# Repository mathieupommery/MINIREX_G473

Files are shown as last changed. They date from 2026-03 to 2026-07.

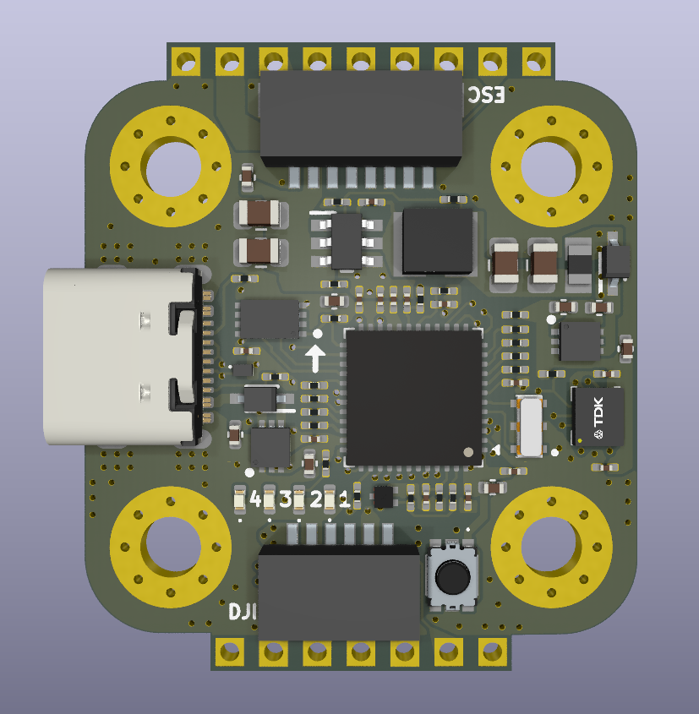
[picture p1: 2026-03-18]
DOC/front.png

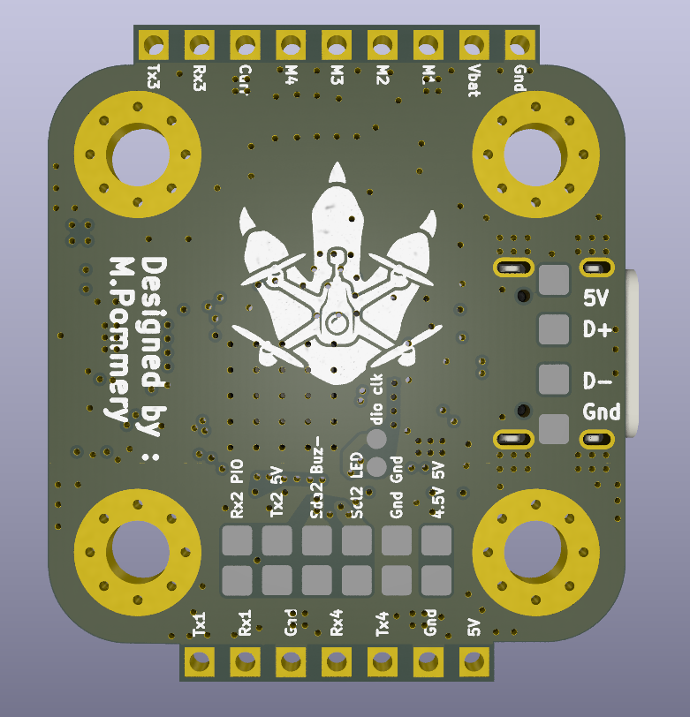
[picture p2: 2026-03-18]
DOC/back.png

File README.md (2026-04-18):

# STM32G473 Flight Controller (20x20mm)

# NEWS : 
* V2 reduced cost by changing part of the compoment to asian brand, assembly now possible with jlc and lcsc part stock, a price per unit produced graph is disponible below 

## Overview
High-performance flight controller based on the **STM32G473** MCU, featuring a compact 20x20mm mounting pattern. This board is specifically designed for high-voltage builds (up to 12S) and high-speed processing, utilizing a 6-layer PCB stackup with all components mounted on a single side for optimal integration and cooling.
## Hardware Visuals

### PCB View (V1)
with_coin
### CAD View (V1)

    

## Technical Specifications
### Core System
* **MCU:** STM32G473 (Cortex-M4, 170MHz)
* **IMU:** ICM-42688-P (Ultra-low noise 6-axis gyro)
* **Blackbox:** 16M-bit (2MB) Onboard Flash
* **PCB:** 6-layer, single-sided compoment 

### Power Management
* **Main Buck Regulator:** LMR51625
    * **Input Voltage:** 7V to 55V
    * **Output:** 5V @ 2.5A Max
* **Dual LDO Regulation:** Two independent LDL212PV33R (1.2A each)
    * **LDO 1:** Dedicated to MCU and Flash memory
    * **LDO 2:** Dedicated to the ICM-42688-P sensor for maximum signal purity

### Protection & Hardware Robustness
* **USB Protection:** Integrated **TVS Diodes** (Transient Voltage Suppressors) on the USB port to protect the MCU against electrostatic discharge (ESD) and short-circuits caused by humidity or debris.
* **Filtering:** High-quality ceramic capacitors and dedicated power planes for a low noise floor.

### Connectivity & Interface
* **Connectors:** 2x JST-SH 1.0mm ports (DJI/Digital VTX and ESC)
* **Status LEDs:** 4x Onboard diagnostic LEDs:
    * 2x Betaflight Status (Green/Blue)
    * 1x 3.3V MCU Power
    * 1x 3.3V Sensor Power
    * many soldering pads to add GPS, buzzer, led, or IO 

## Cost (BOM)
## Bill of Materials (BOM) Cost Estimation

The following table demonstrates the estimated component costs based on Mouser volume pricing. The unit price of each component dynamically adapts to the total quantity required for the entire production batch (1, 100, or 1000 boards). 

*Prices are estimates in USD and do not include PCB manufacturing or assembly costs.*

| Component / Value | Mouser Ref. | Qty/Board | Unit Price (1 Bd) | Unit Price (100 Bds) | Unit Price (1k Bds) | Total 1 Bd | Total 100 Bds | Total 1k Bds |
| :--- | :--- | :---: | :---: | :---: | :---: | :---: | :---: | :---: |
| 100n | 710-885012104005 | 13 | $0.080 | $0.010 | $0.004 | $1.04 | $13.00 | $52.00 |
| 10n | 710-885012104014 | 1 | $0.120 | $0.030 | $0.010 | $0.12 | $3.00 | $10.00 |
| 1u | 710-885012105012 | 3 | $0.180 | $0.060 | $0.030 | $0.54 | $18.00 | $90.00 |
| 4.7u | 710-885012105012 | 3 | $0.180 | $0.060 | $0.030 | $0.54 | $18.00 | $90.00 |
| 0.1u | 81-GRM155R62A104ME4J | 1 | $0.100 | $0.020 | $0.010 | $0.10 | $2.00 | $10.00 |
| 2.2u | 710-885012105007 | 1 | $0.220 | $0.080 | $0.040 | $0.22 | $8.00 | $40.00 |
| 2.2u | 81-GRT21BD72A225KE13 | 2 | $0.240 | $0.090 | $0.050 | $0.48 | $18.00 | $100.00 |
| 47u | 81-GRM21BR61A476ME5K | 2 | $0.550 | $0.220 | $0.120 | $1.10 | $44.00 | $240.00 |
| USB4110-GF-A | 710-629722000214 | 1 | $1.150 | $0.850 | $0.650 | $1.15 | $85.00 | $650.00 |
| LED 150040BS73240 (Blue) | 710-150040BS73240 | 1 | $0.260 | $0.120 | $0.080 | $0.26 | $12.00 | $80.00 |
| LED 150040GS73240 (Green) | 710-150040GS73240 | 1 | $0.260 | $0.120 | $0.080 | $0.26 | $12.00 | $80.00 |
| LED 150040RS73240 (Red) | 710-150040RS73240 | 2 | $0.260 | $0.120 | $0.080 | $0.52 | $24.00 | $160.00 |
| STM32G473CEU6 | 511-STM32G473CEU6 | 1 | $7.580 | $5.450 | $4.800 | $7.58 | $545.00 | $4800.00 |
| 5.1k | 667-ERJ-1GNF5101C | 2 | $0.100 | $0.010 | $0.005 | $0.20 | $2.00 | $10.00 |
| 100k | 667-ERJ-1GNF1003C | 2 | $0.100 | $0.010 | $0.005 | $0.20 | $2.00 | $10.00 |
| 10k | 667-ERJ-1GNF1002C | 3 | $0.100 | $0.010 | $0.005 | $0.30 | $3.00 | $15.00 |
| 1k | 667-ERJ-1GNF1001C | 6 | $0.100 | $0.010 | $0.005 | $0.60 | $6.00 | $30.00 |
| 20k | 667-ERJ-1GNF2002C | 1 | $0.100 | $0.010 | $0.005 | $0.10 | $1.00 | $5.00 |
| 19.1k | 667-ERJ-1GNF1912C | 1 | $0.100 | $0.010 | $0.005 | $0.10 | $1.00 | $5.00 |
| 22R | 667-ERJ-1GNF22R0C | 7 | $0.100 | $0.010 | $0.005 | $0.70 | $7.00 | $35.00 |
| 100R | 667-ERJ-1GNF1000C | 1 | $0.100 | $0.010 | $0.005 | $0.10 | $1.00 | $5.00 |
| Ferrite 74279220800 | 710-74279220800 | 1 | $0.140 | $0.040 | $0.020 | $0.14 | $4.00 | $20.00 |
| Inductor 74479335329247 | 710-74479335329247 | 1 | $0.780 | $0.450 | $0.320 | $0.78 | $45.00 | $320.00 |
| JST SH 6-pin | 306-M06BSRSSTBLFSNPP | 1 | $0.640 | $0.420 | $0.310 | $0.64 | $42.00 | $310.00 |
| LDO LDL212PV33R | 511-LDL212PV33R | 2 | $0.530 | $0.380 | $0.280 | $1.06 | $76.00 | $560.00 |
| Flash MX25R1635FZUIH0 | 95-25R1635FZUIH0TR | 1 | $1.840 | $1.150 | $0.950 | $1.84 | $115.00 | $950.00 |
| TVS SP3222-02ETG | 576-SP3222-02ETG | 1 | $0.420 | $0.220 | $0.150 | $0.42 | $22.00 | $150.00 |
| Switch 435151014824 | 710-435151014824 | 1 | $0.850 | $0.520 | $0.380 | $0.85 | $52.00 | $380.00 |
| MOSFET 2N7002KQBZ | 771-2N7002KQBZ | 1 | $0.180 | $0.060 | $0.030 | $0.18 | $6.00 | $30.00 |
| Osc CSTNE8M00GH5C000R0 | 81-CSTNE8M00GH5C000R | 1 | $0.450 | $0.240 | $0.160 | $0.45 | $24.00 | $160.00 |
| IMU ICM-42688-P | 410-ICM-42688-P | 1 | $4.860 | $3.550 | $2.900 | $4.86 | $355.00 | $2900.00 |
| JST SH 8-pin | 306-SM08BSRSSTB | 1 | $0.720 | $0.480 | $0.350 | $0.72 | $48.00 | $350.00 |
| Diode BAT60JFILM | 511-BAT60JFILM | 2 | $0.280 | $0.110 | $0.060 | $0.56 | $22.00 | $120.00 |
| Buck LMR51625YFDDCR | 595-LMR51625YFDDCR | 1 | $1.250 | $0.880 | $0.650 | $1.25 | $88.00 | $650.00 |
| **TOTAL COST (BOM)** | **-** | **-** | **-** | **-** | **-** | **$29.96** | **$1724.00** | **$13417.00** |
| **AVERAGE PRICE PER BOARD** | **-** | **-** | **-** | **-** | **-** | **$29.96** | **$17.24** | **$13.42** |

## Cost (BOM) V2
V2 version is here for cost optimisation purposes and for the possibility to assemble it completly on jlcpcb with lcsc compoment part, i changed few compoment like Nmos for buzzer or boot button, and i priviledged asian brand here is a graph with the cost per unit according to unit produced : 

costvsunit

## Hardware Design Principles
The 6-layer design ensures superior EMI shielding and thermal dissipation. 
stackup: signal-gnd-signal-gnd-power-gnd   
provide shielded power from signal and from the outside.

## Result and test : 

### Before reflow : 
before_reflow

###  Mounted on apex evo 5 inch : 

mounted

###  Test in fly :

> La vidéo de démonstration est disponible ici : [DOC/image_v1/video.mp4](./DOC/v1_image/vid.mp4)

## License
Creative Commons Attribution-NonCommercial-ShareAlike 4.0 International.

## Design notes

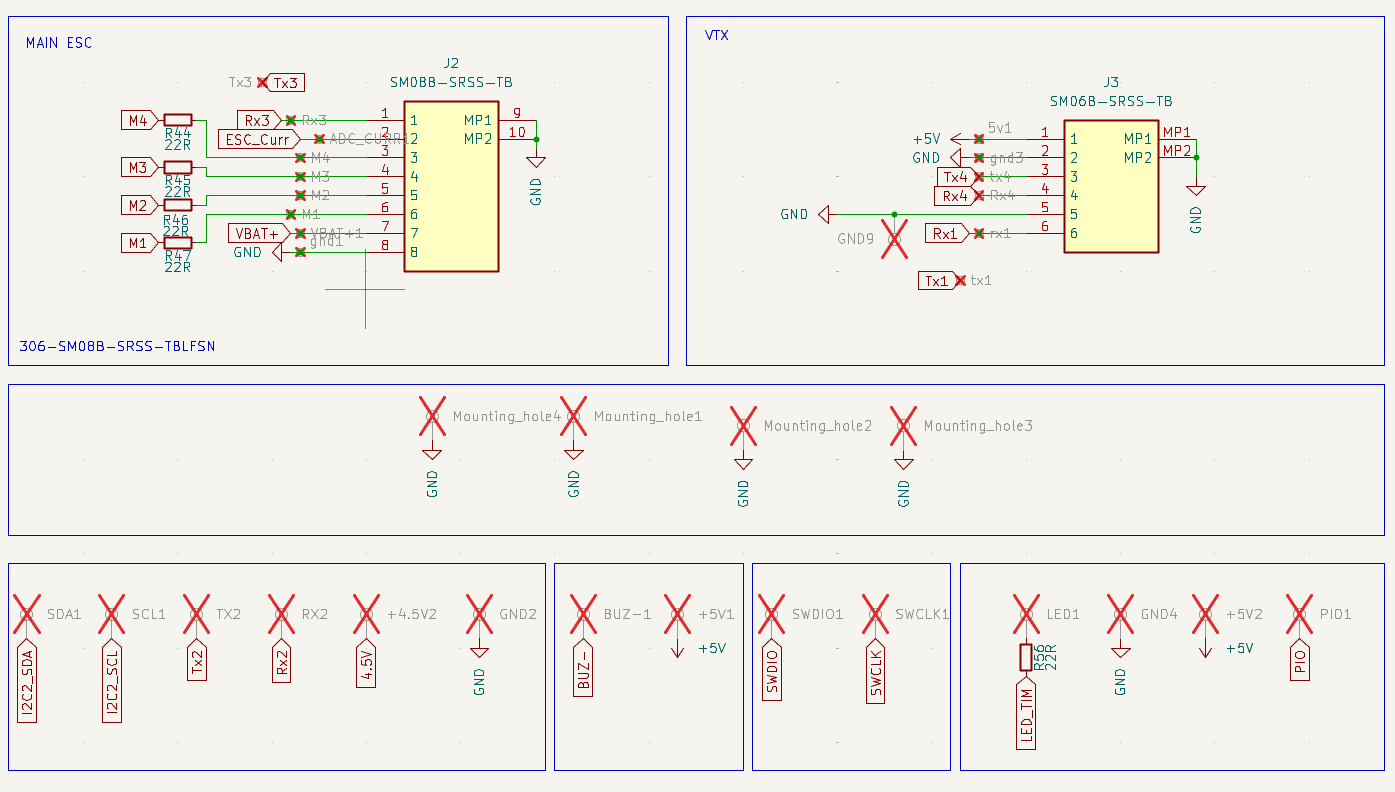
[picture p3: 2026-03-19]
DOC/sh4.png

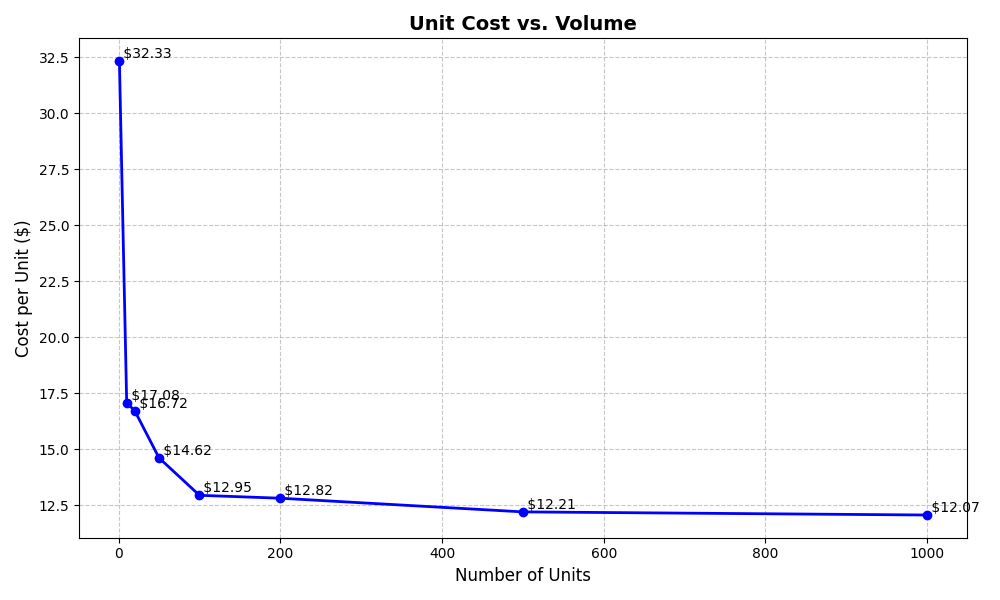
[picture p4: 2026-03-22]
DOC/costvsunit.png

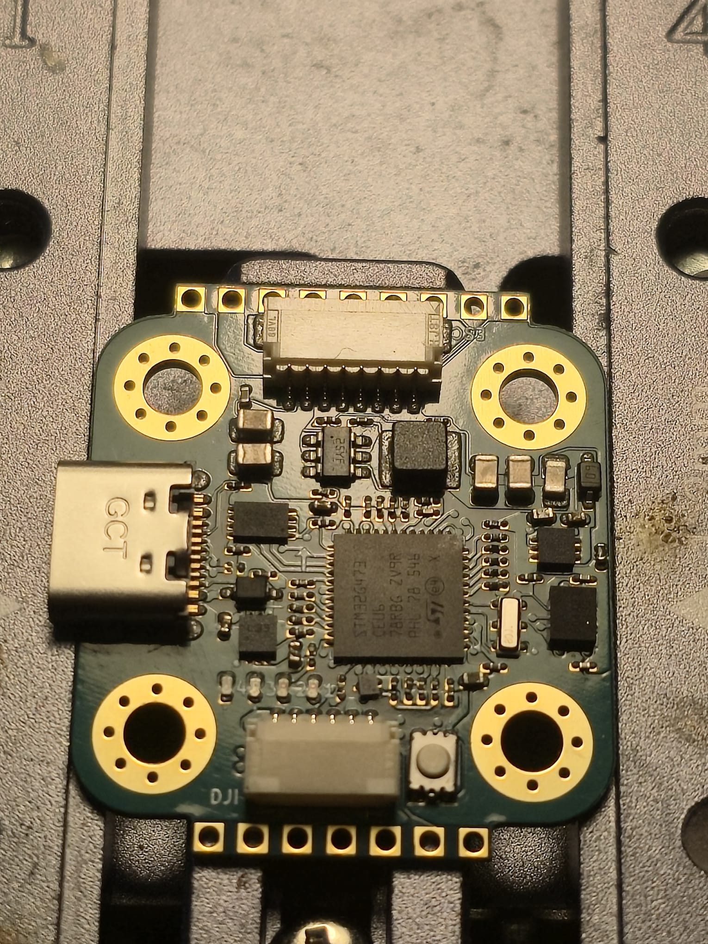
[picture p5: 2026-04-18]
DOC/v1_image/before_reflow.jpeg

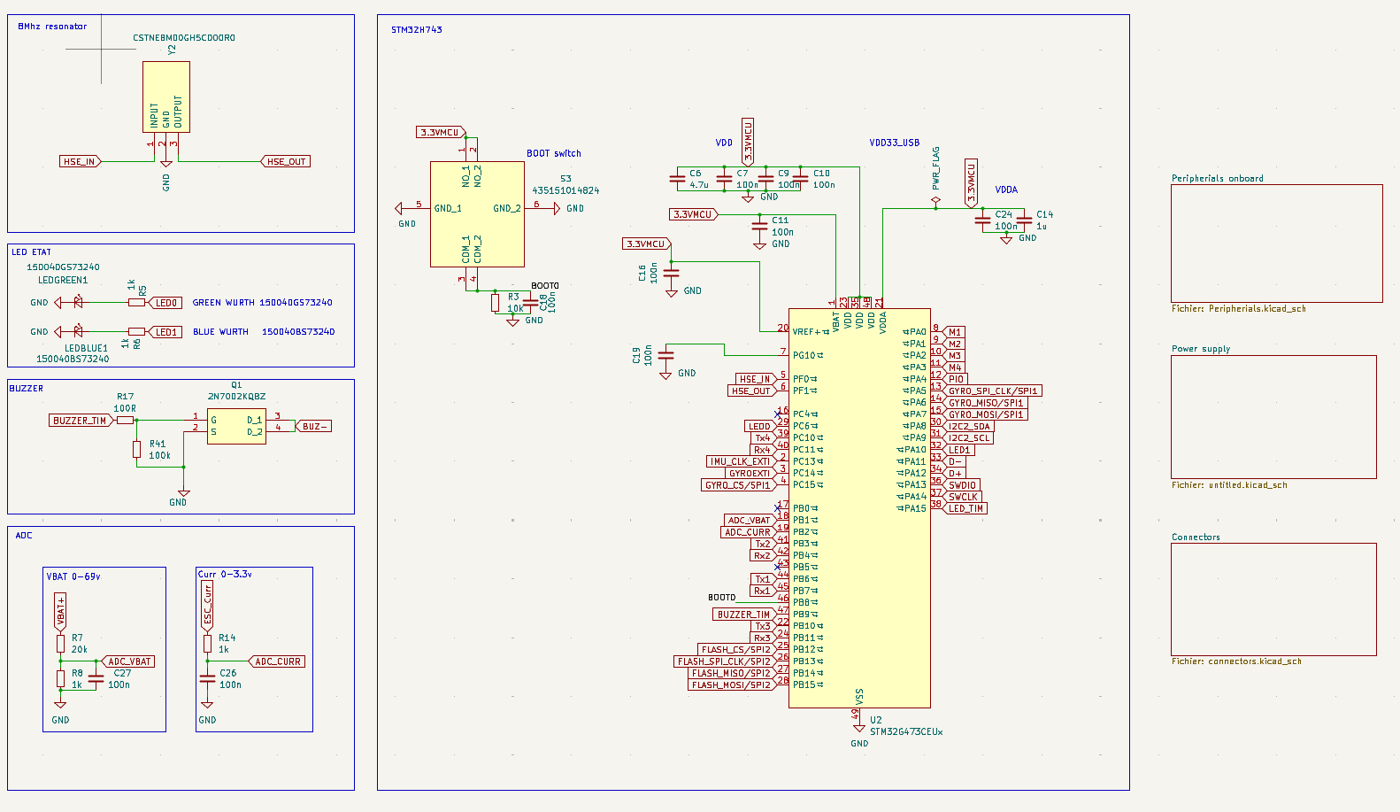
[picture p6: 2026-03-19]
DOC/sh1.png

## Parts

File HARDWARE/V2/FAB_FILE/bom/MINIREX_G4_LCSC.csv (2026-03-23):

Designator | Comment | Manufacturer_Part_Number | LCSC Part Number
LEDRED3,LEDRED4 | 150040RS73240 | TZ-P2-0402RTIA1-0.45T | C779449
LEDGREEN1 | 150040GS73240 | SZYY0402G | C434446
LEDBLUE1 | 150040BS73240 | XL-1005UBC | C22355736
L1 | ZEPIM303020D-4R7M | ZEPIM303020D-4R7M | C49009083
J1 | USB4105-GF-A | USB4105-GF-A | C3025063
FB1 | MPZ2012S101ATD25 | MPZ2012S101ATD25 | C307776
C21 | 2.2u | CC0402KRX5R7BB225 | C326556
C7,C9,C10,C11,C12,C16,C18,C19,C20,C22,C24,C25,C26,C27 | 100n | CC0201KRX5R8BB104 | C718252
C2,C6,C23 | 4.7u | CC0402MRX5R7BB475 | C723999
C1,C3,C14 | 1u | CC0402KRX5R7BB105 | C325464
IC2 | LMR51625YFDDCR | LMR51625YFDDCR | C45262768
IC1 | ICM-42688P | ICM-42688P | C46550687
U2 | STM32G473CEUx | STM32G473CEU6 | C1342773
IC4,IC5 | LDL212PV33R | LDL212PV33R | C2969892
D10,D11 | BAT60JFILM | BAT60JFILM | C133103
S1 | TS2306A-240GF-MSM-9_C388290 | TS2306A-240GF-MSM-9_C388290 | C2976675
R13,R17,R44,R45,R46,R47,R56,R61 | 47R | RC0201FR-0747RL | C273279
R5,R6,R8,R14,R21,R22 | 1k | RC0201FR-071KL | C138165
R3,R7,R9,R11,R15 | 19.1k | RC0201FR-0719K6L | C474565
R2,R41 | 100k | RC0201FR-07100KL | C106224
R1,R10 | 5.1k | RC0201FR-075K1L | C274341
Q2 | PMZB150UNEYL | TPM2025NP3 | C49230916
Y2 | CSTNE8M00GH5C000R0 | CSTNE8M00GH5C000R0 | C341525
C8,C17 | 47u | GRM21BR61A476ME15K | C2292827
C5 | 0.1u | GRM155R62A104KE14D | C162178
C4,C13 | 2.2u | GRM21BD72A225KE01L | C2981733
IC3 | ZD25WQ32CEIGR | ZD25WQ32CEIGR | C5258281
D1 | TPSP3222-02ETG | TPSP3222-02ETG | C47117640
J3 | SM06B-SRSS-TB | SM06B-SRSS-TB | C160405
J2 | SM08B-SRSS-TB | SM08B-SRSS-TB | C160407

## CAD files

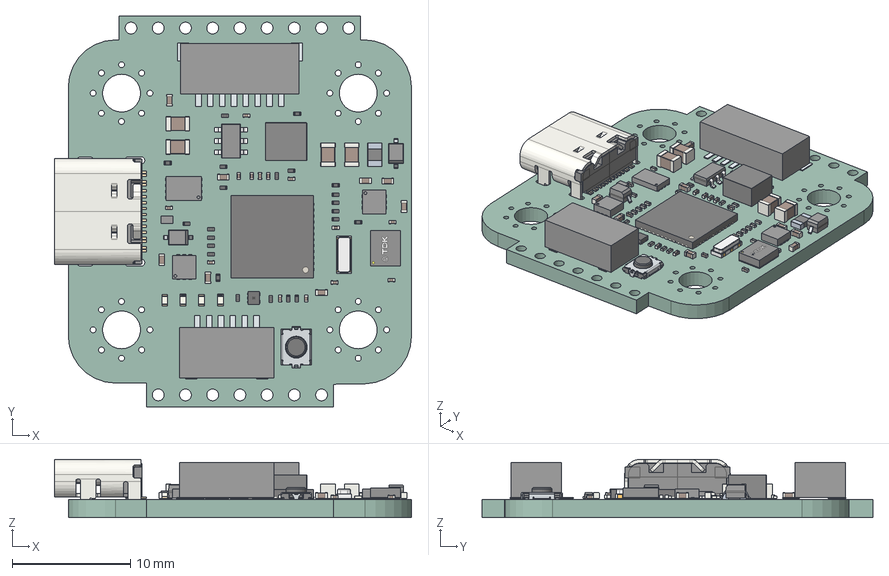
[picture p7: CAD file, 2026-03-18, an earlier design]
HARDWARE/V1/3D/v1.step
30.2 x 33.0 x 4.91 mm
C_0805_2012Metric x 4
R_0201_0603Metric x 23
C_0201_0603Metric x 14
Pins x 3
LED_0402_1005Metric x 4
SOT8015 LF
SOT8015 Body
C_0402_1005Metric x 8
CSTNE8M00GH5C000R0
BODY-SOT
LEAD-SOT x 6
USB_C_Receptacle_GCT_USB4105-xx-A_16P_TopMnt_Horizontal
ICM-42688-P
FilletPinL x 2
FilletPinR x 2
QFN-48-1EP_7x7mm_P0.5mm_EP5.15x5.15mm
ThermalPin x 3
PinsArrayLR x 3
Lötende x 2
Base
Stem
Frame
Pin x 4
FC_H7_MINI_PCB

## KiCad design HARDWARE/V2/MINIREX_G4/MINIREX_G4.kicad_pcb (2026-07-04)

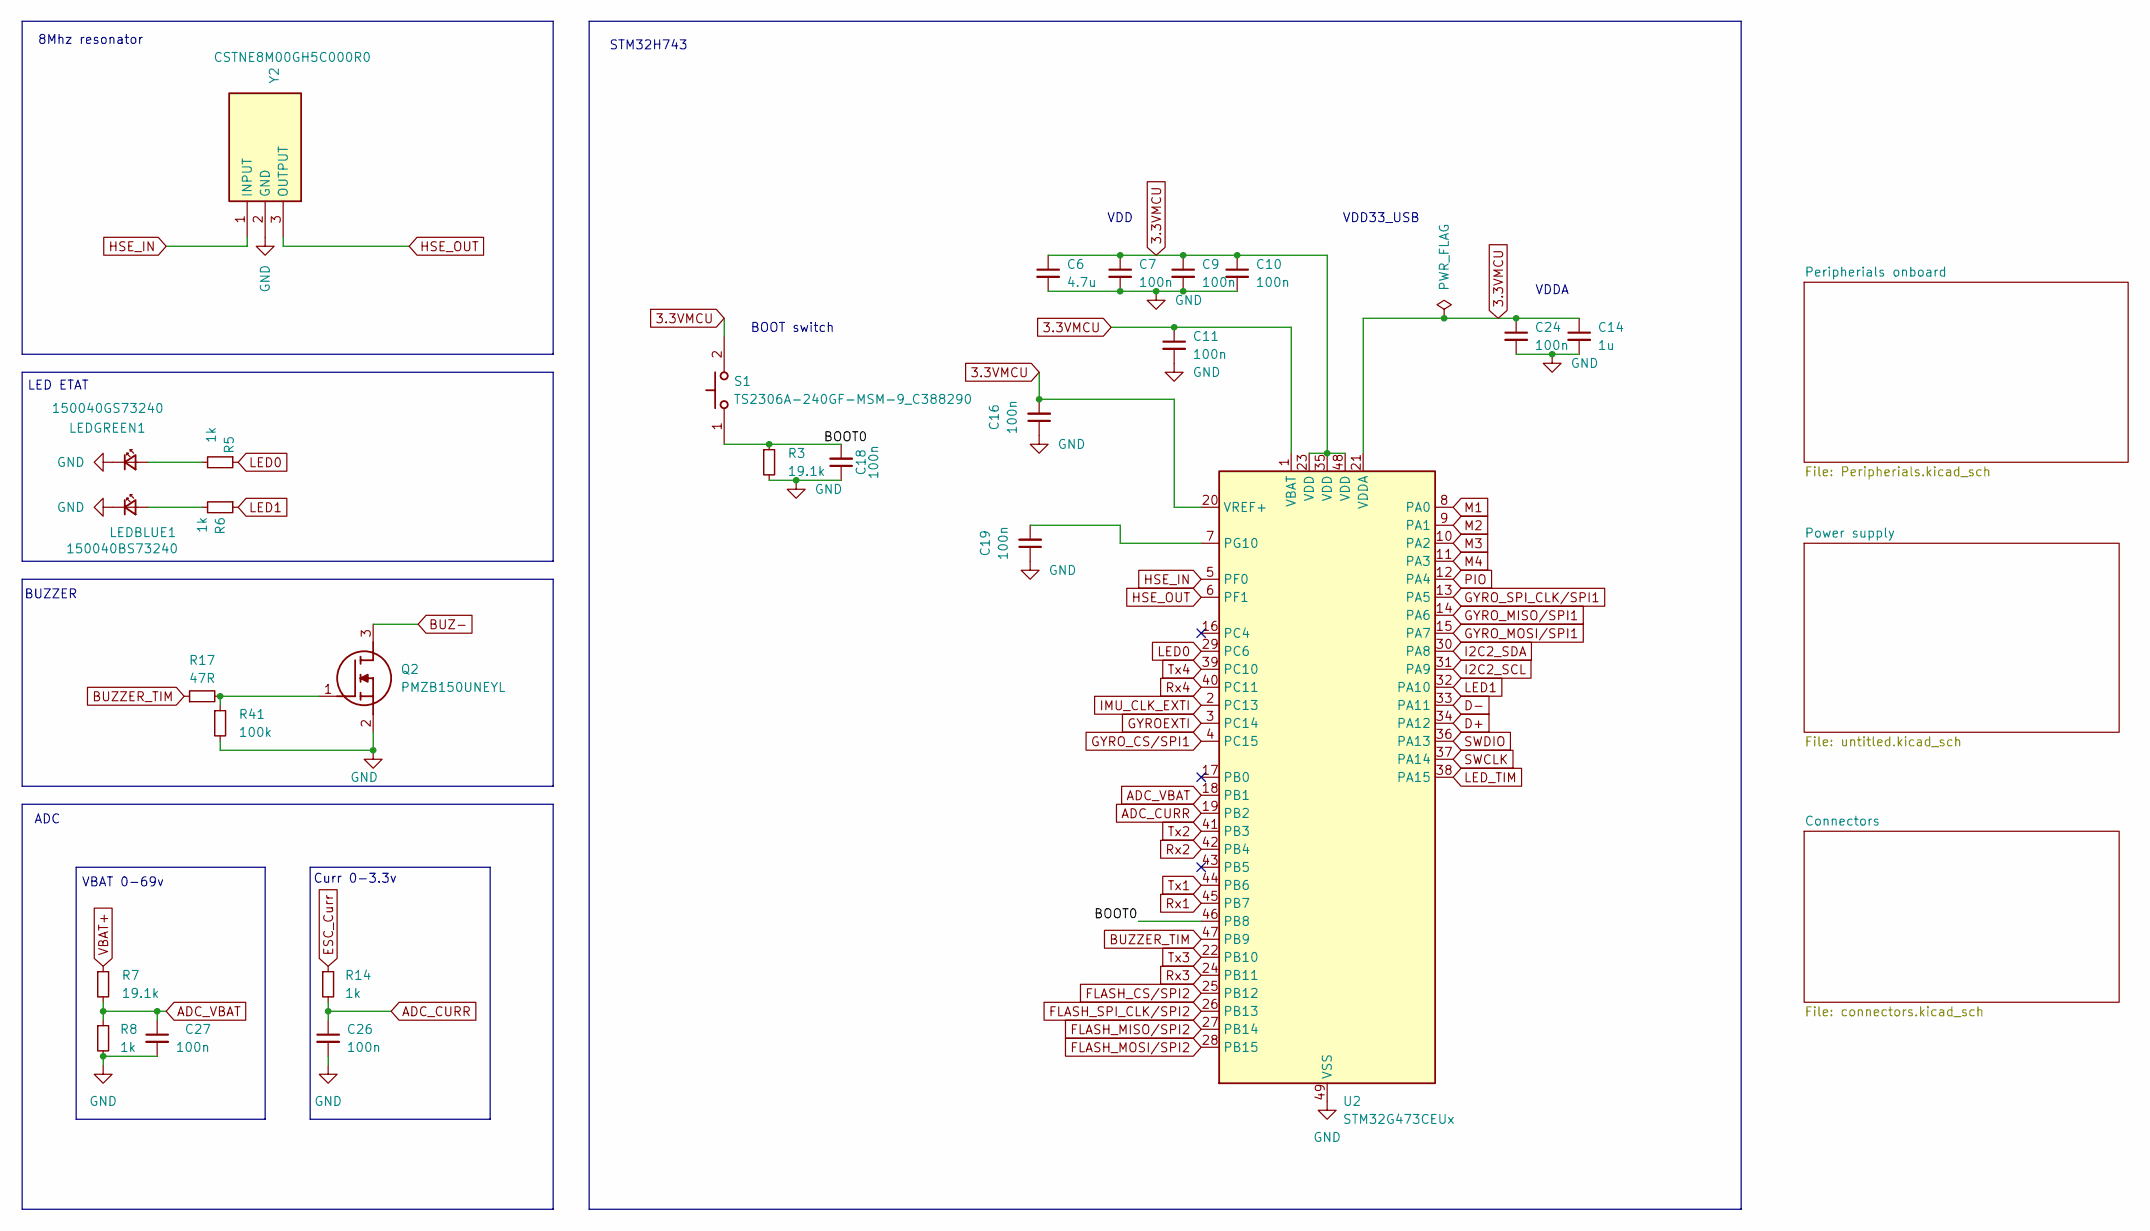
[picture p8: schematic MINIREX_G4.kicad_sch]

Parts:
C6: 4.7u; C_0402_1005Metric; Manufacturer_Part_Number CC0402MRX5R7BB475; Mouser Part Number 710-885012105012
C7, C9, C10, C11, C16, C18, C19, C24, C26, C27: 100n; C_0201_0603Metric_Pad0.64x0.40mm_HandSolder; Manufacturer_Part_Number CC0201KRX5R8BB104; Mouser Part Number 710-885012104005
C14: 1u; C_0402_1005Metric; Manufacturer_Part_Number CC0402KRX5R7BB105; Mouser Part Number 710-885012105012
LEDBLUE1: 150040BS73240; LED_0402_1005Metric; Manufacturer_Part_Number XL-1005UBC; Mouser Part Number 710-150040BS73240
LEDGREEN1: 150040GS73240; LED_0402_1005Metric; Manufacturer_Part_Number SZYY0402G; Mouser Part Number 710-150040GS73240
Q2: PMZB150UNEYL; Manufacturer_Part_Number TPM2025NP3; Mouser Part Number 771-PMZB150UNEYL
R3, R7: 19.1k; R_0201_0603Metric_Pad0.64x0.40mm_HandSolder; Manufacturer_Part_Number RC0201FR-0719K6L; Mouser Part Number 667-ERJ-1GNF1002C
R5, R6, R8, R14: 1k; R_0201_0603Metric_Pad0.64x0.40mm_HandSolder; Manufacturer_Part_Number RC0201FR-071KL; Mouser Part Number 667-ERJ-1GNF1001C
R17: 47R; R_0201_0603Metric_Pad0.64x0.40mm_HandSolder; Manufacturer_Part_Number RC0201FR-0747RL; Mouser Part Number 667-ERJ-1GNF22R0C
R41: 100k; R_0201_0603Metric_Pad0.64x0.40mm_HandSolder; Manufacturer_Part_Number RC0201FR-07100KL; Mouser Part Number 667-ERJ-1GNF1003C
S1: TS2306A-240GF-MSM-9_C388290; TS2306A240GFMSM9_C388290; Manufacturer_Part_Number TS2306A-240GF-MSM-9_C388290; LCSC Part Number C2976675
U2: STM32G473CEUx; QFN-48-1EP_7x7mm_P0.5mm_EP5.6x5.6mm; Manufacturer_Part_Number STM32G473CEU6; Mouser Part Number 511-STM32G473CEU6
Y2: CSTNE8M00GH5C000R0; CSTNE12M0GH5L000R0; Mouser Part Number 81-CSTNE8M00GH5C000R

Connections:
3.3VMCU: C6.1, C7.1, C9.1, C10.1, C11.1, C14.1, C16.2, C24.1, S1.2 (COM), U2.1 (VBAT), U2.20 (VREF+), U2.21 (VDDA), U2.23 (VDD), U2.35 (VDD), U2.48 (VDD); also elsewhere on the board
/BOOT0: C18.2, R3.1, S1.1 (NO), U2.46 (PB8)
ADC_CURR: C26.1, R14.2, U2.19 (PB2)
ADC_VBAT: C27.1, R7.2, R8.1, U2.18 (PB1)
BUZ-: Q2.3 (D); also elsewhere on the board
BUZZER_TIM: R17.1, U2.47 (PB9)
D+: U2.34 (PA12); also elsewhere on the board
D-: U2.33 (PA11); also elsewhere on the board
ESC_Curr: R14.1; also elsewhere on the board
FLASH_CS/SPI2: U2.25 (PB12); also elsewhere on the board
FLASH_MISO/SPI2: U2.27 (PB14); also elsewhere on the board
FLASH_MOSI/SPI2: U2.28 (PB15); also elsewhere on the board
FLASH_SPI_CLK/SPI2: U2.26 (PB13); also elsewhere on the board
GND: C6.2, C7.2, C9.2, C10.2, C11.2, C14.2, C16.1, C18.1, C19.1, C24.2, C26.2, C27.2, LEDBLUE1.1 (K), LEDGREEN1.1 (K), Q2.2 (S), R3.2, R8.2, R41.2, U2.49 (VSS), Y2.2 (GND); also elsewhere on the board
GYROEXTI: U2.3 (PC14); also elsewhere on the board
GYRO_CS/SPI1: U2.4 (PC15); also elsewhere on the board
GYRO_MISO/SPI1: U2.14 (PA6); also elsewhere on the board
GYRO_MOSI/SPI1: U2.15 (PA7); also elsewhere on the board
GYRO_SPI_CLK/SPI1: U2.13 (PA5); also elsewhere on the board
HSE_IN: U2.5 (PF0), Y2.1 (INPUT)
HSE_OUT: U2.6 (PF1), Y2.3 (OUTPUT)
I2C2_SCL: U2.31 (PA9); also elsewhere on the board
I2C2_SDA: U2.30 (PA8); also elsewhere on the board
IMU_CLK_EXTI: U2.2 (PC13); also elsewhere on the board
LED0: R5.1, U2.29 (PC6)
LED1: R6.1, U2.32 (PA10)
LED_TIM: U2.38 (PA15); also elsewhere on the board
M1: U2.8 (PA0); also elsewhere on the board
M2: U2.9 (PA1); also elsewhere on the board
M3: U2.10 (PA2); also elsewhere on the board
M4: U2.11 (PA3); also elsewhere on the board
unnamed: LEDBLUE1.2 (A), R6.2
unnamed: LEDGREEN1.2 (A), R5.2
unnamed: Q2.1 (G), R17.2, R41.1
unnamed: C19.2, U2.7 (PG10)
PIO: U2.12 (PA4); also elsewhere on the board
Rx1: U2.45 (PB7); also elsewhere on the board
Rx2: U2.42 (PB4); also elsewhere on the board
Rx3: U2.24 (PB11); also elsewhere on the board
Rx4: U2.40 (PC11); also elsewhere on the board
SWCLK: U2.37 (PA14); also elsewhere on the board
SWDIO: U2.36 (PA13); also elsewhere on the board
Tx1: U2.44 (PB6); also elsewhere on the board
Tx2: U2.41 (PB3); also elsewhere on the board
Tx3: U2.22 (PB10); also elsewhere on the board
Tx4: U2.39 (PC10); also elsewhere on the board
VBAT+: R7.1; also elsewhere on the board

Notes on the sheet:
VDD33_USB
VDDA
BUZZER
STM32H743
ADC
Curr 0-3.3v
LED ETAT
BOOT switch
VDD
8Mhz resonator
VBAT 0-69v

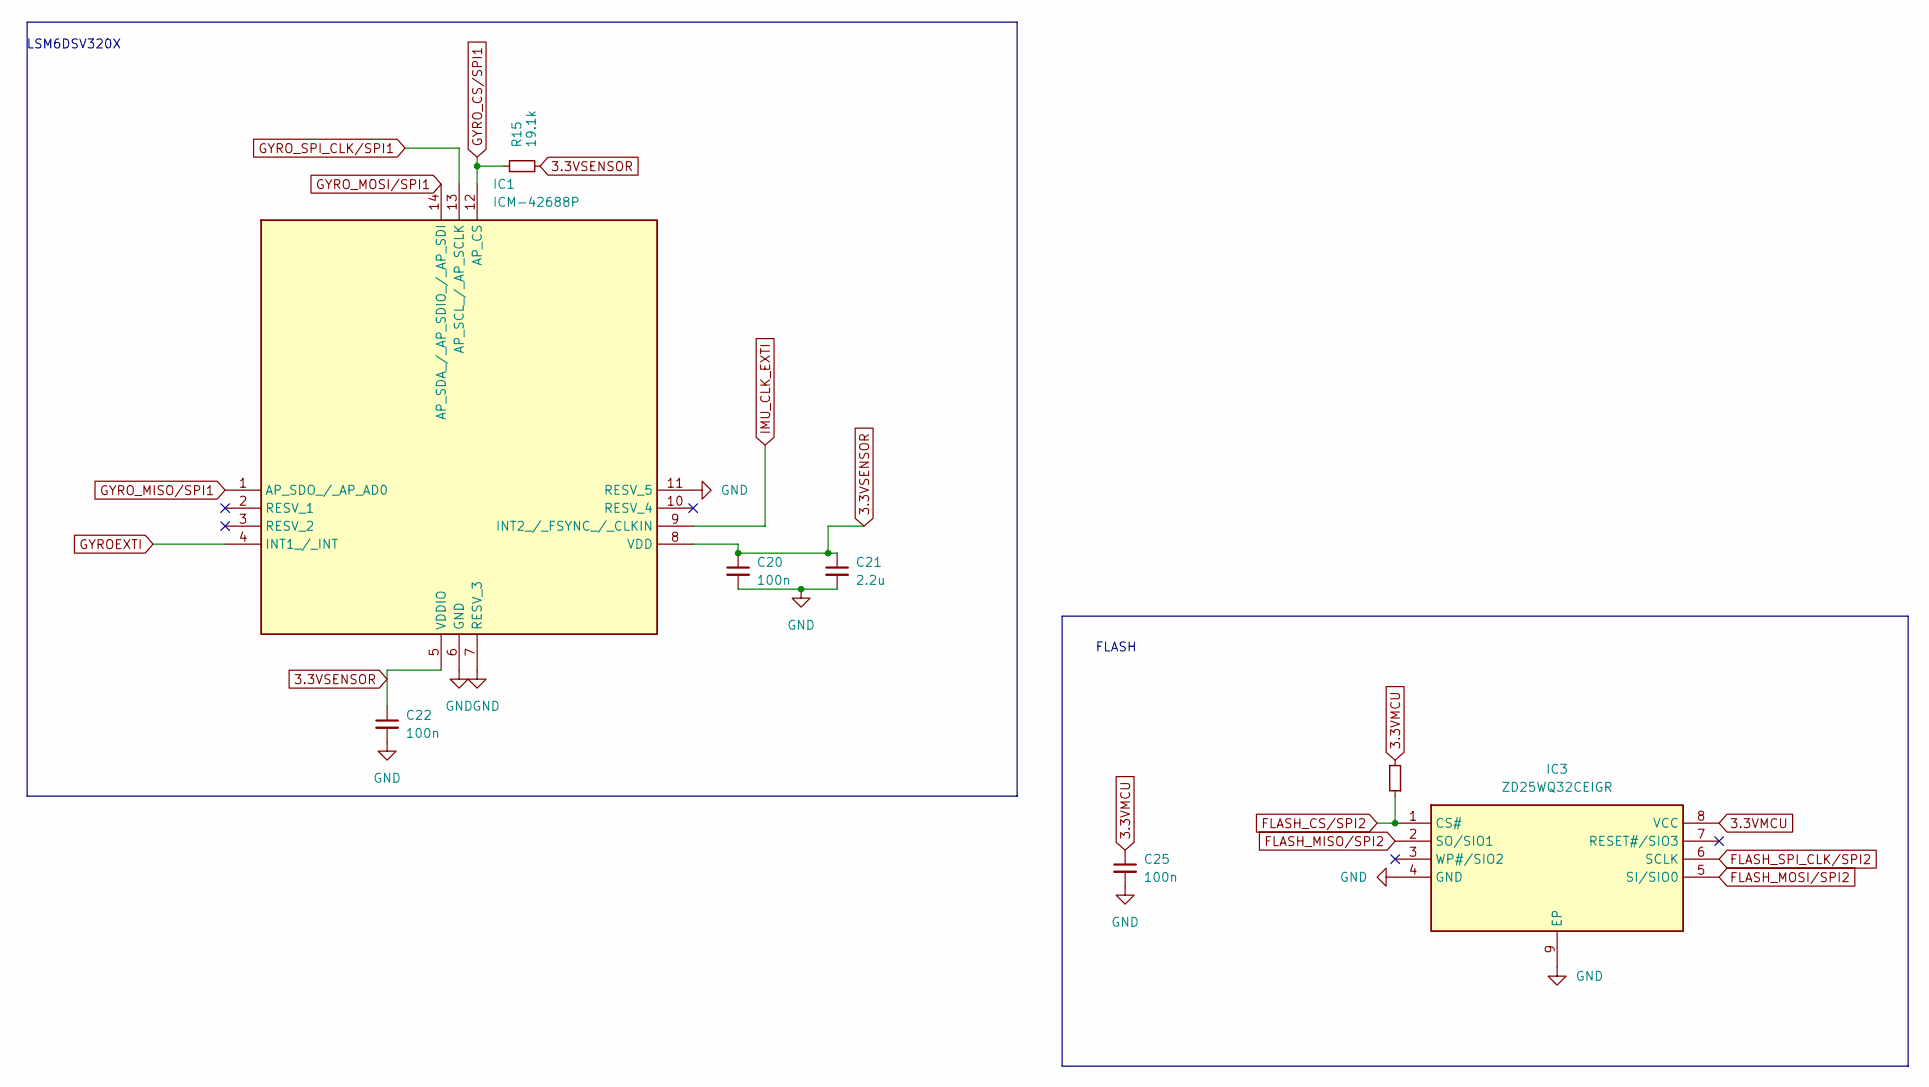
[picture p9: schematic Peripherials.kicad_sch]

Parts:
C20, C25: 100n; C_0201_0603Metric_Pad0.64x0.40mm_HandSolder; Manufacturer_Part_Number CC0201KRX5R8BB104; Mouser Part Number 710-885012104005
C21: 2.2u; C_0402_1005Metric; Manufacturer_Part_Number CC0402KRX5R7BB225; Mouser Part Number 710-885012105007
C22: 100n; C_0201_0603Metric_Pad0.64x0.40mm_HandSolder; Manufacturer_Part_Number CC0201KRX5R8BB104; Mouser Part Number 710-885012104014
IC1: ICM-42688P; IIM42352; Mouser Part Number 410-ICM-42688-P
IC3: ZD25WQ32CEIGR; SON50P300X200X60-9N; Manufacturer_Part_Number ZD25WQ32CEIGR; Mouser Part Number 95-25R1635FZUIH0TR
R9, R15: 19.1k; R_0201_0603Metric_Pad0.64x0.40mm_HandSolder; Manufacturer_Part_Number RC0201FR-0719K6L; Mouser Part Number 667-ERJ-1GNF1002C

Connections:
3.3VMCU: C25.1, IC3.8 (VCC), R9.2; also elsewhere on the board
3.3VSENSOR: C20.1, C21.1, C22.1, IC1.5 (VDDIO), IC1.8 (VDD), R15.2; also elsewhere on the board
FLASH_CS/SPI2: IC3.1 (CS#), R9.1; also elsewhere on the board
FLASH_MISO/SPI2: IC3.2 (SO/SIO1); also elsewhere on the board
FLASH_MOSI/SPI2: IC3.5 (SI/SIO0); also elsewhere on the board
FLASH_SPI_CLK/SPI2: IC3.6 (SCLK); also elsewhere on the board
GND: C20.2, C21.2, C22.2, C25.2, IC1.6 (GND), IC1.7 (RESV_3), IC1.11 (RESV_5), IC3.4 (GND), IC3.9 (EP); also elsewhere on the board
GYROEXTI: IC1.4 (INT1_/_INT); also elsewhere on the board
GYRO_CS/SPI1: IC1.12 (AP_CS), R15.1; also elsewhere on the board
GYRO_MISO/SPI1: IC1.1 (AP_SDO_/_AP_AD0); also elsewhere on the board
GYRO_MOSI/SPI1: IC1.14 (AP_SDA_/_AP_SDIO_/_AP_SDI); also elsewhere on the board
GYRO_SPI_CLK/SPI1: IC1.13 (AP_SCL_/_AP_SCLK); also elsewhere on the board
IMU_CLK_EXTI: IC1.9 (INT2_/_FSYNC_/_CLKIN); also elsewhere on the board

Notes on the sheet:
FLASH
LSM6DSV320X

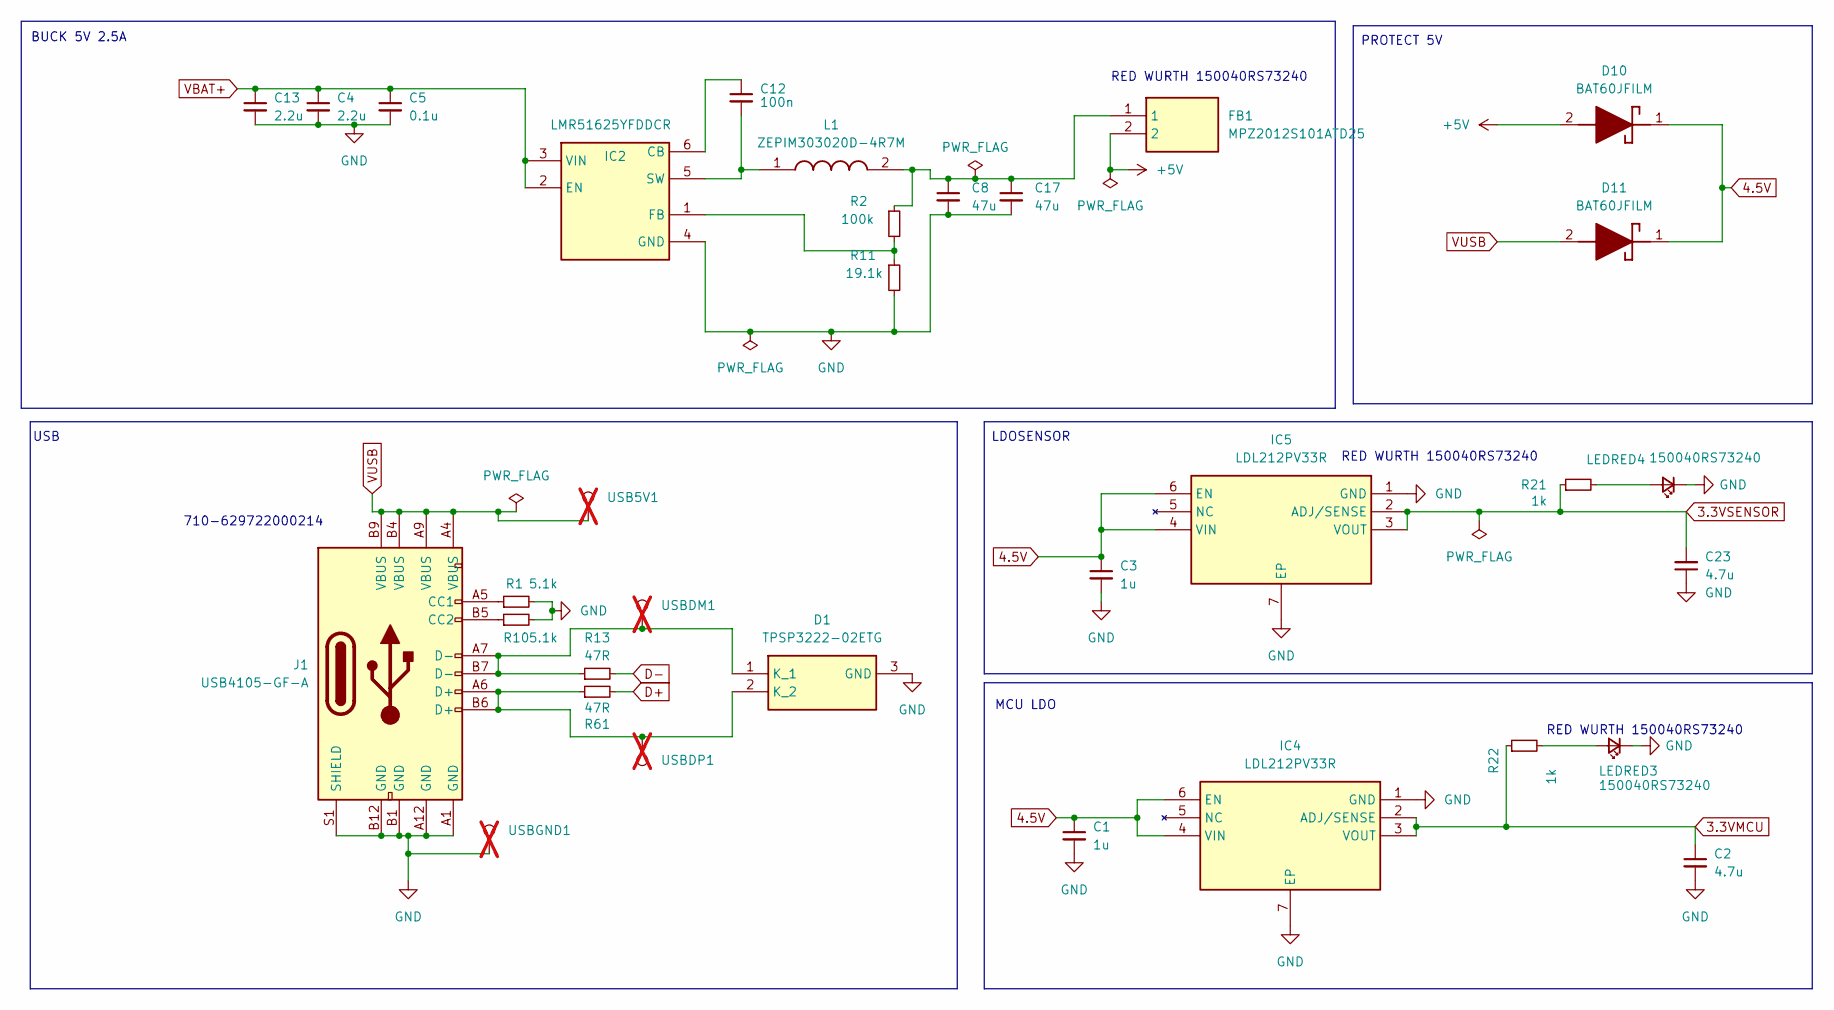
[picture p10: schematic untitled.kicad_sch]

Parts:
C1, C3: 1u; C_0402_1005Metric; Manufacturer_Part_Number CC0402KRX5R7BB105; Mouser Part Number 710-885012105012
C2, C23: 4.7u; C_0402_1005Metric; Manufacturer_Part_Number CC0402MRX5R7BB475; Mouser Part Number 710-885012105012
C4, C13: 2.2u; C_0805_2012Metric; Manufacturer_Part_Number GRM21BD72A225KE01L; Mouser Part Number 81-GRT21BD72A225KE13
C5: 0.1u; C_0402_1005Metric; Manufacturer_Part_Number GRM155R62A104KE14D; Mouser Part Number 81-GRM155R62A104ME4J
C8, C17: 47u; C_0805_2012Metric; Manufacturer_Part_Number GRM21BR61A476ME15K; Mouser Part Number 81-GRM21BR61A476ME5K
C12: 100n; C_0201_0603Metric_Pad0.64x0.40mm_HandSolder; Manufacturer_Part_Number CC0201KRX5R8BB104; Mouser Part Number 710-885012104005
D1: TPSP3222-02ETG; SP322202ETG; Manufacturer_Part_Number TPSP3222-02ETG; Mouser Part Number 576-SP3222-02ETG
D10, D11: BAT60JFILM; SOD2513X117N; Mouser Part Number 511-BAT60JFILM
FB1: MPZ2012S101ATD25; BEADC2012X90N; Manufacturer_Part_Number MPZ2012S101ATD25; Mouser Part Number 710-74279220800
IC2: LMR51625YFDDCR; SOT95P280X110-6N; Manufacturer_Part_Number LMR51625YFDDCR; Mouser Part Number 595-LMR51625YFDDCR
IC4, IC5: LDL212PV33R; SON50P200X200X80-7N-D; Manufacturer_Part_Number LDL212PV33R; Mouser Part Number 511-LDL212PV33R
J1: USB4105-GF-A; USB_C_Receptacle_GCT_USB4105-xx-A_16P_TopMnt_Horizontal; Manufacturer_Part_Number USB4105-GF-A; Mouser Part Number 710-629722000214
L1: ZEPIM303020D-4R7M; INDC3532X200N; Manufacturer_Part_Number ZEPIM303020D-4R7M; Mouser Part Number 710-74479335329247
LEDRED3, LEDRED4: 150040RS73240; LED_0402_1005Metric; Manufacturer_Part_Number TZ-P2-0402RTIA1-0.45T; Mouser Part Number 710-150040RS73240
R1, R10: 5.1k; R_0201_0603Metric_Pad0.64x0.40mm_HandSolder; Manufacturer_Part_Number RC0201FR-075K1L; Mouser Part Number 667-ERJ-1GNF5101C
R2: 100k; R_0201_0603Metric_Pad0.64x0.40mm_HandSolder; Manufacturer_Part_Number RC0201FR-07100KL; Mouser Part Number 667-ERJ-1GNF1003C
R11: 19.1k; R_0201_0603Metric_Pad0.64x0.40mm_HandSolder; Manufacturer_Part_Number RC0201FR-0719K6L; Mouser Part Number 667-ERJ-1GNF1002C
R13, R61: 47R; R_0201_0603Metric_Pad0.64x0.40mm_HandSolder; Manufacturer_Part_Number RC0201FR-0747RL; Mouser Part Number 667-ERJ-1GNF22R0C
R21, R22: 1k; R_0201_0603Metric_Pad0.64x0.40mm_HandSolder; Manufacturer_Part_Number RC0201FR-071KL; Mouser Part Number 667-ERJ-1GNF1001C
USB5V1: TestPoint; PAD_1.5mmx1.5mm; not fitted
USBDM1: TestPoint; PAD_1.5mmx1.5mm; not fitted
USBDP1: TestPoint; PAD_1.5mmx1.5mm; not fitted
USBGND1: TestPoint; PAD_1.5mmx1.5mm; not fitted

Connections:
3.3VMCU: C2.1, IC4.2 (ADJ/SENSE), IC4.3 (VOUT), R22.1; also elsewhere on the board
3.3VSENSOR: C23.2, IC5.2 (ADJ/SENSE), IC5.3 (VOUT), R21.1; also elsewhere on the board
4.5V: C1.1, C3.1, D10.1 (K), D11.1 (K), IC4.4 (VIN), IC4.6 (EN), IC5.4 (VIN), IC5.6 (EN); also elsewhere on the board
+5V: D10.2 (A), FB1.2; also elsewhere on the board
D+: R61.2; also elsewhere on the board
D-: R13.2; also elsewhere on the board
GND: C1.2, C2.2, C3.2, C4.2, C5.2, C8.2, C13.2, C17.2, C23.1, D1.3 (GND), IC2.4 (GND), IC4.1 (GND), IC4.7 (EP), IC5.1 (GND), IC5.7 (EP), J1.A1 (GND), J1.A12 (GND), J1.B1 (GND), J1.B12 (GND), J1.S1 (SHIELD), LEDRED3.1 (K), LEDRED4.1 (K), R1.2, R10.2, R11.2, USBGND1.1; also elsewhere on the board
unnamed: C8.1, C17.1, FB1.1, L1.2, R2.1
unnamed: D1.1 (K_1), J1.A7 (D-), J1.B7 (D-), R13.1, USBDM1.1
unnamed: D1.2 (K_2), J1.A6 (D+), J1.B6 (D+), R61.1, USBDP1.1
unnamed: C12.1, IC2.6 (CB)
unnamed: IC2.1 (FB), R2.2, R11.1
unnamed: C12.2, IC2.5 (SW), L1.1
unnamed: J1.A5 (CC1), R1.1
unnamed: J1.B5 (CC2), R10.1
unnamed: LEDRED3.2 (A), R22.2
unnamed: LEDRED4.2 (A), R21.2
VBAT+: C4.1, C5.1, C13.1, IC2.2 (EN), IC2.3 (VIN); also elsewhere on the board
VUSB: D11.2 (A), J1.A4 (VBUS), J1.A9 (VBUS), J1.B4 (VBUS), J1.B9 (VBUS), USB5V1.1

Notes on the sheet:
LDOSENSOR
PROTECT 5V
RED WURTH 150040RS73240
BUCK 5V 2.5A
MCU LDO
USB
710-629722000214

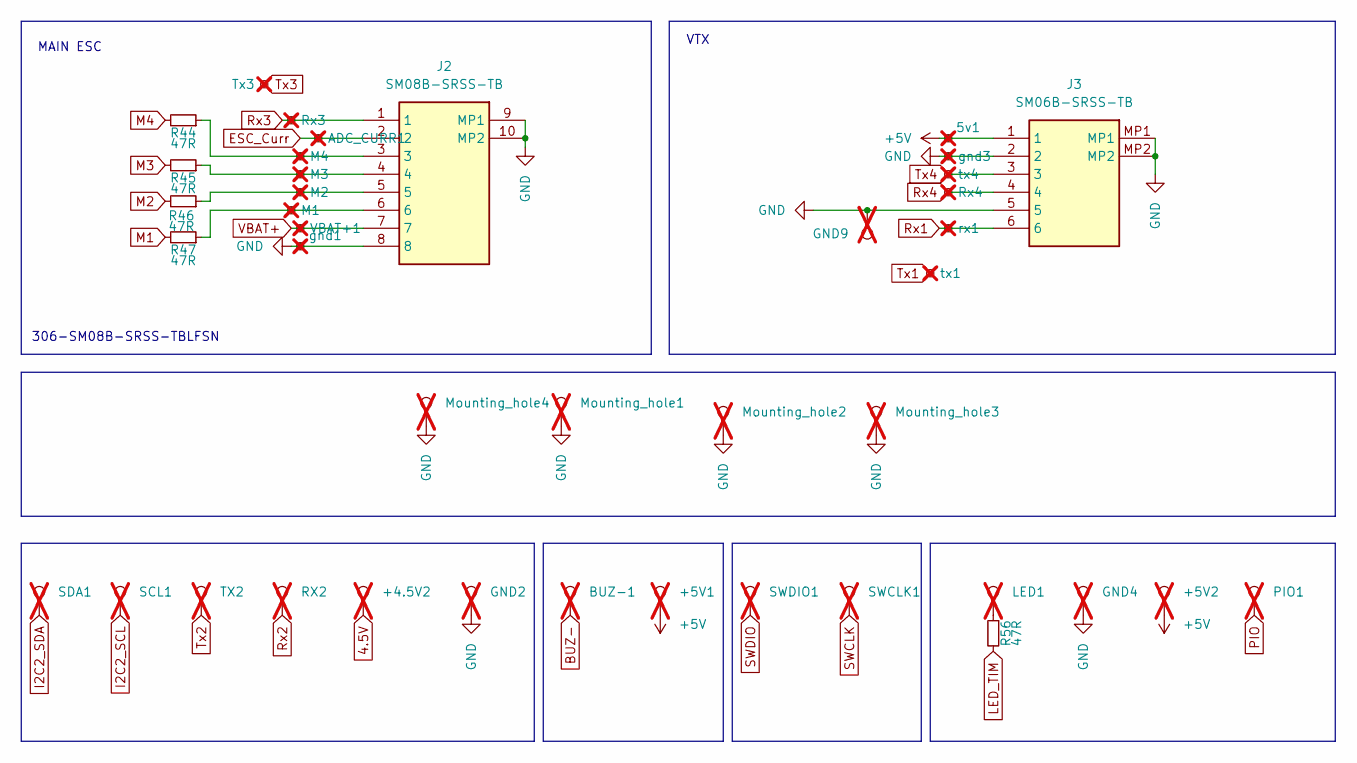
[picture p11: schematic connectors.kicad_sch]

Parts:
5v1: TestPoint_Small; PAD_1.5mmx1.5mm_hole; not fitted
+4.5V2, +5V1, +5V2: TestPoint; PAD_1.5mmx1.5mm; not fitted
ADC_CURR1: TestPoint_Small; PAD_1.5mmx1.5mm_hole; not fitted
BUZ-1: TestPoint; PAD_1.5mmx1.5mm; not fitted
GND2, GND4: TestPoint; PAD_1.5mmx1.5mm; not fitted
GND9: TestPoint; PAD_1.5mmx1.5mm_hole; not fitted
J2: SM08B-SRSS-TB; SM08BSRSSTB; Manufacturer_Part_Number SM08B-SRSS-TB; Mouser Part Number 306-SM08BSRSSTB
J3: SM06B-SRSS-TB; SM06BSRSSTB; Manufacturer_Part_Number SM06B-SRSS-TB; Mouser Part Number 306-M06BSRSSTBLFSNPP
LED1: TestPoint; PAD_1.5mmx1.5mm; not fitted
M1, M2, M3, M4: TestPoint_Small; PAD_1.5mmx1.5mm_hole; not fitted
Mounting_hole1, Mounting_hole2, Mounting_hole3, Mounting_hole4: TestPoint; MountingHole_3.2mm_M3_Pad_Via; not fitted
PIO1: TestPoint; PAD_1.5mmx1.5mm; not fitted
R44, R45, R46, R47, R56: 47R; R_0201_0603Metric_Pad0.64x0.40mm_HandSolder; Manufacturer_Part_Number RC0201FR-0747RL; Mouser Part Number 667-ERJ-1GNF22R0C
RX2: TestPoint; PAD_1.5mmx1.5mm; not fitted
Rx3, Rx4: TestPoint_Small; PAD_1.5mmx1.5mm_hole; not fitted
SCL1: TestPoint; PAD_1.5mmx1.5mm; not fitted
SDA1: TestPoint; PAD_1.5mmx1.5mm; not fitted
SWCLK1: TestPoint; 1mm_circle; not fitted
SWDIO1: TestPoint; 1mm_circle; not fitted
TX2: TestPoint; PAD_1.5mmx1.5mm; not fitted
Tx3: TestPoint_Small; PAD_1.5mmx1.5mm_hole; not fitted
VBAT+1: TestPoint_Small; PAD_1.5mmx1.5mm_hole; not fitted
gnd1, gnd3: TestPoint_Small; PAD_1.5mmx1.5mm_hole; not fitted
rx1: TestPoint_Small; PAD_1.5mmx1.5mm_hole; not fitted
tx1, tx4: TestPoint_Small; PAD_1.5mmx1.5mm_hole; not fitted

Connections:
4.5V: +4.5V2.1; also elsewhere on the board
+5V: 5v1.1, +5V1.1, +5V2.1, J3.1; also elsewhere on the board
BUZ-: BUZ-1.1; also elsewhere on the board
ESC_Curr: ADC_CURR1.1, J2.2; also elsewhere on the board
GND: GND2.1, GND4.1, GND9.1, J2.8, J2.9 (MP1), J2.10 (MP2), J3.2, J3.5, J3.MP1, J3.MP2, Mounting_hole1.1, Mounting_hole2.1, Mounting_hole3.1, Mounting_hole4.1, gnd1.1, gnd3.1; also elsewhere on the board
I2C2_SCL: SCL1.1; also elsewhere on the board
I2C2_SDA: SDA1.1; also elsewhere on the board
LED_TIM: R56.2; also elsewhere on the board
M1: R47.2; also elsewhere on the board
M2: R46.2; also elsewhere on the board
M3: R45.2; also elsewhere on the board
M4: R44.2; also elsewhere on the board
unnamed: J2.3, M4.1, R44.1
unnamed: J2.4, M3.1, R45.1
unnamed: J2.5, M2.1, R46.1
unnamed: J2.6, M1.1, R47.1
unnamed: LED1.1, R56.1
PIO: PIO1.1; also elsewhere on the board
Rx1: J3.6, rx1.1; also elsewhere on the board
Rx2: RX2.1; also elsewhere on the board
Rx3: J2.1, Rx3.1; also elsewhere on the board
Rx4: J3.4, Rx4.1; also elsewhere on the board
SWCLK: SWCLK1.1; also elsewhere on the board
SWDIO: SWDIO1.1; also elsewhere on the board
Tx1: tx1.1; also elsewhere on the board
Tx2: TX2.1; also elsewhere on the board
Tx3: Tx3.1; also elsewhere on the board
Tx4: J3.3, tx4.1; also elsewhere on the board
VBAT+: J2.7, VBAT+1.1; also elsewhere on the board

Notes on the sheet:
MAIN ESC
306-SM08B-SRSS-TBLFSN
VTX

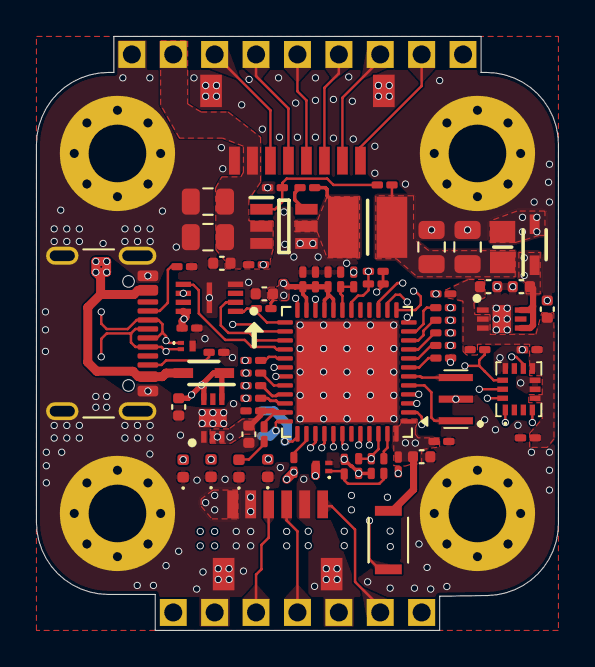
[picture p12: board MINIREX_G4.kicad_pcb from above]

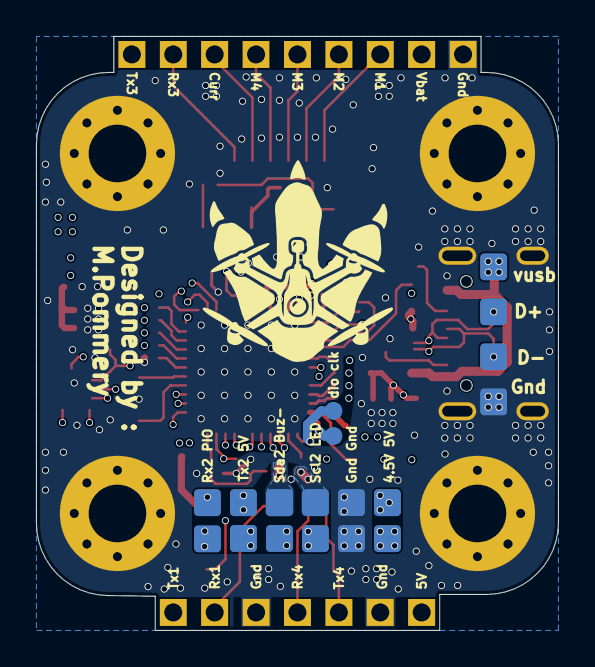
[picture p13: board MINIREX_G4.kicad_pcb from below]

Board: 6 copper layers, 29.0 x 33.0 mm, 108 parts (18 on the bottom side), 66 nets.

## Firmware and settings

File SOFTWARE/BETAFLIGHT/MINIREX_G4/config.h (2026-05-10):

/*
 * This file is part of Betaflight.
 *
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
 * See the GNU General Public License for more details.
 *
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
 * If not, see <http://www.gnu.org/licenses/>.
 */

#pragma once

#define FC_TARGET_MCU     STM32G47X

#define BOARD_NAME        MINIREX_G4
#define MANUFACTURER_ID   POMMERY

#define USE_ACC
#define USE_ACC_SPI_ICM42688P
#define USE_GYRO
#define USE_GYRO_CLKIN
#define USE_GYRO_SPI_ICM42688P
#define USE_FLASH
#define USE_FLASH_M25P16

#define BEEPER_PIN           PB9

#define MOTOR1_PIN           PA0
#define MOTOR2_PIN           PA1
#define MOTOR3_PIN           PA2
#define MOTOR4_PIN           PA3


#define LED_STRIP_PIN        PA15

#define UART1_TX_PIN         PB6
#define UART2_TX_PIN         PB3
#define UART3_TX_PIN         PB10
#define UART4_TX_PIN         PC10

#define UART1_RX_PIN         PB7
#define UART2_RX_PIN         PB4
#define UART3_RX_PIN         PB11
#define UART4_RX_PIN         PC11

#define I2C2_SCL_PIN         PA9
#define I2C2_SDA_PIN         PA8

#define LED0_PIN             PC6
#define LED1_PIN             PA10



#define SPI1_SCK_PIN         PA5
#define SPI1_SDI_PIN         PA6
#define SPI1_SDO_PIN         PA7
#define GYRO_1_CS_PIN        PC15
#define GYRO_1_EXTI_PIN      PC14
#define GYRO1_CLKIN_PIN      PC13
#define GYRO_1_SPI_INSTANCE  SPI1


#define SPI2_SCK_PIN         PB13
#define SPI2_SDI_PIN         PB14
#define SPI2_SDO_PIN         PB15
#define FLASH_CS_PIN         PB12
#define FLASH_SPI_INSTANCE   SPI2


#define ADC_VBAT_PIN         PB1
#define ADC_CURR_PIN         PB2


#define PINIO1_PIN           PA4

#define TIMER_PIN_MAPPING \
    TIMER_PIN_MAP( 1, MOTOR1_PIN , 2,  0) \
    TIMER_PIN_MAP( 2, MOTOR2_PIN , 2,  1) \
    TIMER_PIN_MAP( 3, MOTOR3_PIN , 2,  2) \
    TIMER_PIN_MAP( 4, MOTOR4_PIN , 2,  3) \
    TIMER_PIN_MAP( 5, LED_STRIP_PIN , 1,  4) \
    TIMER_PIN_MAP( 6, GYRO1_CLKIN_PIN , 1, -1) 

#define TIMUP2_DMA_OPT      0
#define ADC1_DMA_OPT        8
#define ADC2_DMA_OPT        7

#define DEFAULT_RX_FEATURE FEATURE_RX_SERIAL
#define SERIALRX_UART      SERIAL_PORT_USART1

#define DEFAULT_BLACKBOX_DEVICE      BLACKBOX_DEVICE_FLASH


#define DEFAULT_CURRENT_METER_SOURCE CURRENT_METER_ADC
#define DEFAULT_VOLTAGE_METER_SOURCE VOLTAGE_METER_ADC
#define DEFAULT_VOLTAGE_METER_SCALE  210
#define BEEPER_PWM_HZ 2500

#define PINIO1_BOX 40
#define GYRO_1_ALIGN                 CW0_DEG

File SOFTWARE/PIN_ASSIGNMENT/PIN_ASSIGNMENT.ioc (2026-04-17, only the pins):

Mcu.UserName=STM32G473CEUx
PA0.Signal=S_TIM2_CH1
PA1.Signal=S_TIM2_CH2
PA11.Signal=USB_DM
PA12.Signal=USB_DP
PA13.Signal=SYS_JTMS-SWDIO
PA14.Signal=SYS_JTCK-SWCLK
PA15.Signal=S_TIM8_CH1
PA2.Signal=S_TIM2_CH3
PA3.Signal=S_TIM2_CH4
PA5.Signal=SPI1_SCK
PA6.Signal=SPI1_MISO
PA7.Signal=SPI1_MOSI
PA8.Signal=I2C2_SDA
PA9.Signal=I2C2_SCL
PB1.Signal=ADC1_IN12
PB10.Signal=USART3_TX
PB11.Signal=USART3_RX
PB12.Signal=SPI2_NSS
PB13.Signal=SPI2_SCK
PB14.Signal=SPI2_MISO
PB15.Signal=SPI2_MOSI
PB2.Signal=ADC2_IN12
PB3.Signal=USART2_TX
PB4.Signal=USART2_RX
PB6.Signal=USART1_TX
PB7.Signal=USART1_RX
PB9.Signal=S_TIM8_CH3
PC10.Signal=UART4_TX
PC11.Signal=UART4_RX
PF0-OSC_IN.Signal=RCC_OSC_IN
PF1-OSC_OUT.Signal=RCC_OSC_OUT

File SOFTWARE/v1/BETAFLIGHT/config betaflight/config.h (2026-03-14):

/*
 * This file is part of Betaflight.
 *
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
 * See the GNU General Public License for more details.
 *
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
 * If not, see <http://www.gnu.org/licenses/>.
 */

#pragma once

#define FC_TARGET_MCU     STM32H743

#define BOARD_NAME        ADROHA_H7
#define MANUFACTURER_ID   ADROHA

#define USE_ACC
#define USE_ACC_SPI_ICM42688P
#define USE_GYRO
#define USE_GYRO_SPI_ICM42688P
#define USE_BARO
#define USE_BARO_DPS310
#define USE_MAX7456
#define USE_SDCARD

#define BEEPER_PIN           PA15

#define MOTOR1_PIN           PA0
#define MOTOR2_PIN           PA1
#define MOTOR3_PIN           PA2
#define MOTOR4_PIN           PA3

#define MOTOR5_PIN           PD13
#define MOTOR6_PIN           PD12
#define MOTOR7_PIN           PD14
#define MOTOR8_PIN           PD15

#define SERVO1_PIN           PB1
#define SERVO2_PIN           PB0

#define RX_PPM_PIN           PC7

#define LED_STRIP_PIN        PA8

#define UART1_TX_PIN         PA9
#define UART3_TX_PIN         PD8
#define UART4_TX_PIN         PB9
#define UART6_TX_PIN         PC6
#define UART7_TX_PIN         PE8
#define UART8_TX_PIN         PE1

#define UART1_RX_PIN         PA10
#define UART3_RX_PIN         PD9
#define UART4_RX_PIN         PB8
#define UART6_RX_PIN         PC7
#define UART7_RX_PIN         PE7
#define UART8_RX_PIN         PE0


#define I2C1_SCL_PIN         PB6
#define I2C1_SDA_PIN         PB7

#define I2C2_SCL_PIN         PB10
#define I2C2_SDA_PIN         PB11

#define LED0_PIN             PE3
#define LED1_PIN             PE4



#define SPI1_SCK_PIN         PA5
#define SPI1_SDI_PIN         PA6
#define SPI1_SDO_PIN         PD7
#define GYRO_1_CS_PIN        PC15



#define SPI2_SCK_PIN         PB13
#define SPI2_SDI_PIN         PB14
#define SPI2_SDO_PIN         PB15
#define MAX7456_SPI_CS_PIN   PB12




#define ADC_VBAT_PIN         PC0
#define ADC_CURR_PIN         PA7
#define ADC_EXTERNAL2_PIN    PA4  //ADC12  VB2 
#define ADC_EXTERNAL3_PIN    PC1  //ADC12  CU2


#define SDIO_CK_PIN          PC12
#define SDIO_CMD_PIN         PD2
#define SDIO_D0_PIN          PC8
#define SDIO_D1_PIN          PC9
#define SDIO_D2_PIN          PC10
#define SDIO_D3_PIN          PC11

#define PINIO1_PIN           PC14
#define PINIO2_PIN           PD11

#define GYRO_1_EXTI_PIN      PB2


#define TIMER_PIN_MAPPING \
    TIMER_PIN_MAP( 0, PB0 , 2,  0) \
    TIMER_PIN_MAP( 1, PB1 , 2,  0) \
    TIMER_PIN_MAP( 2, PA0 , 2,  0) \
    TIMER_PIN_MAP( 3, PA1 , 2,  0) \
    TIMER_PIN_MAP( 4, PA2 , 2,  0) \
    TIMER_PIN_MAP( 5, PA3 , 2,  0) \
    TIMER_PIN_MAP( 6, PD12, 1,  0) \
    TIMER_PIN_MAP( 7, PD13, 1,  0) \
    TIMER_PIN_MAP( 8, PE5 , 1, -1) \
    TIMER_PIN_MAP( 9, PE6 , 1, -1) \
    TIMER_PIN_MAP(10, PA8 , 1,  0) \
    TIMER_PIN_MAP(11, PA15, 1, -1) \
    TIMER_PIN_MAP(12, PC7 , 2, -1) 



#define ADC1_DMA_OPT        8
#define ADC3_DMA_OPT        9
#define TIMUP1_DMA_OPT      0
#define TIMUP2_DMA_OPT      0
#define TIMUP3_DMA_OPT      2
#define TIMUP4_DMA_OPT      1
#define TIMUP5_DMA_OPT      0
#define TIMUP8_DMA_OPT      0

#define BARO_I2C_INSTANCE I2CDEV_2

#define DEFAULT_RX_FEATURE FEATURE_RX_SERIAL

#define DEFAULT_BLACKBOX_DEVICE     BLACKBOX_DEVICE_SDCARD
#define DEFAULT_CURRENT_METER_SOURCE CURRENT_METER_ADC
#define DEFAULT_VOLTAGE_METER_SOURCE VOLTAGE_METER_ADC
#define DEFAULT_VOLTAGE_METER_SCALE_DEFAULT 210
#define DEFAULT_CURRENT_METER_SCALE 150
#define BEEPER_PWM_HZ 2500

#define SDCARD_DETECT_PIN NONE
#define SDIO_DEVICE SDIODEV_1
#define SDIO_USE_4BIT 1
#define MAX7456_SPI_INSTANCE SPI2

#define PINIO1_BOX 40
#define PINIO2_BOX 41
#define GYRO_1_SPI_INSTANCE SPI1

#define ENSURE_MPU_DATA_READY_IS_LOW

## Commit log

2026-03-18 Create README.md for STM32G473 Flight Controller
    Added detailed specifications, features, and visuals for the STM32G473 flight controller.
2026-03-18 Enhance README with visuals and BOM details
    Updated hardware visuals and technical specifications, including cost breakdown and component details.
2026-03-19 picture add
    [MINIREX_G4.kicad_pcb, MINIREX_G4.kicad_sch]
2026-03-22 Add news section to README
    Added news section detailing cost reduction and assembly options.
2026-04-18 Update hardware visuals in README
    Updated hardware visuals section with images for PCB and CAD views.

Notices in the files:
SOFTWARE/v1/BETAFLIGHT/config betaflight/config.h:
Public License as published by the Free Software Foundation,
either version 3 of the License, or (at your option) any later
